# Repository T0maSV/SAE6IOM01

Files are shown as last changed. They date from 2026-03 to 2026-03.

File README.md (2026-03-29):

# Simulateur de Parking Connecté — SAÉ6.IOM.01

> **Livrable final : [`VIALON_Thomas_rapport_final.pdf`](./VIALON_Thomas-rapport_final.pdf)** (Livrable 6)

## Présentation

Projet de fin d'études réalisé dans le cadre du BUT Réseaux & Télécommunications, parcours Internet des Objets et Mobilité (IOM), à l'IUT de Blois — Année universitaire 2025-2026.

Le projet consiste en la conception et la réalisation d'une maquette fonctionnelle de parking connecté intégrant :

- Détection de véhicules par trois technologies de capteurs (effet Hall, Reed/ILS, infrarouge)
- Communication longue portée LoRa 868 MHz entre les capteurs et le serveur
- Contrôle d'accès par badge RFID (13.56 MHz) avec barrière motorisée et sécurité anti-écrasement par capteur ultrason
- Serveur embarqué sur Raspberry Pi 3 (Flask, InfluxDB, SQLite)
- Interface Web de supervision accessible depuis le Raspberry Pi 4 commun

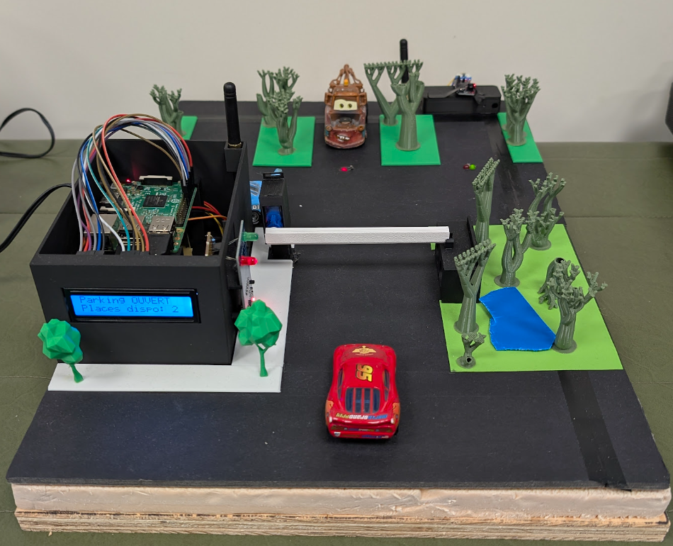
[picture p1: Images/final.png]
Maquette du simulateur de parking connecté


## Arborescence du dépôt
```
├── VIALON_Thomas_rapport_final.pdf   # Livrable 6 — Rapport final
├── VIALON_CdCT_V1.pdf               # Livrables 2 & 3 — Cahier des Charges Technique
├── VIALON_Thomas_Devis.pdf           # Livrable 4 — Devis
├── diagramme_gantt.png               # Livrable 1 — Diagramme de Gantt
│
├── Programme/                        # Intégralité des programmes du projet
│   └── Final/
│       ├── ESP_Parking/              # ESP32 LoRa — Nœud capteur (3 places)
│       ├── ESP_Passerelle/           # ESP32 LoRa — Gateway LoRa/Série
│       ├── ESP_Barrier/              # ESP32 — Contrôleur d'accès (RFID + barrière)
│       └── RPi3/                     # Raspberry Pi 3 — Serveur (app.py, index.html, reset_db.py)
│
├── 3D/                               # Modélisation et fichiers d'impression 3D
│   ├── Maquette Parking.shapr.step   # Projet complet (ensemble des pièces)
│
├── Fritzing/                         # Schémas électroniques (CAO)
│   └── *.fzz                         # Circuits réalisés et envisagés pour le projet
│
└── Images/                           # Photos et captures du projet
```

## Technologies utilisées

| Domaine | Technologies |
|---|---|
| Communication sans fil | LoRa 868 MHz, Wi-Fi 2.4 GHz, RFID 13.56 MHz |
| Microcontrôleurs | ESP32 (Heltec LoRa V2), ESP32 DevKit |
| Serveur | Raspberry Pi 3, Python, Flask |
| Bases de données | InfluxDB (séries temporelles), SQLite (utilisateurs/badges) |
| Électronique | PCB gravés par CNC (Fritzing), soudure manuelle |
| Fabrication | Impression 3D PLA, modélisation Shapr3D |

## Auteur

**Thomas VIALON** — BUT R&T 3ᵉ année, parcours IOM — IUT de Blois

Encadrant : M. Xavier JEANNERET

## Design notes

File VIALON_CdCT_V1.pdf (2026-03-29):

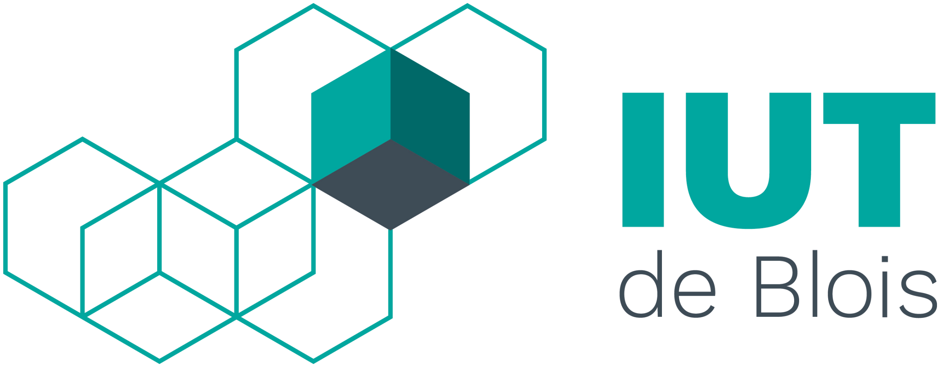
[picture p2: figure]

IUT DE BLOIS

Département Réseaux et Télécommunications

## CAHIER DES CHARGES TECHNIQUE

# SAE6IOM01

## Simulateur d’un parking connecté

Auteur :
Thomas VIALON

Date de remise :
11 février 2026

Document technique universitaire - Usage pédagogique uniquement

## Suivi des modifications

Version | Date | Auteur | Description des modifications
0.1 | 03/02/2026 | T. VIALON | Création du document et analyse du besoin (CdCF).
0.5 | 05/02/2026 | T. VIALON | Définition de l’architecture technique (Hardware/Software) et choix des so-lutions.
0.9 | 10/02/2026 | T. VIALON | Ajout du budget prévisionnel et du planning (Gantt). Rédaction des scé-narios.
1.0 | 11/02/2026 | T. VIALON | Validation finale pour diffusion. Mise en forme et intégration des sché-mas.

## Liste de diffusion

— Destinataire : M. Xavier JEANNERET (Enseignant responsable et client)

CdCT - Simulateur Parking | SAE6IOM01

## Table des matières

1 Introduction et Contexte | 3
2 Solutions Techniques et Matériel | 6
3 Organisation Générale de la Solution | 10
4 Budget Prévisionnel | 12
5 Calendrier Prévisionnel | 13

## 1 Introduction et Contexte

### 1.1 Rappel du besoin (CdCF)

Le besoin exprimé consiste a concevoir la maquette d’un parking connecté. Le client attend notamment de ce projet les fonctionnalités suivantes :
— Collecte des données avec historique : places occupés, temps occupé, contrôle d’accès.
— Affichage local du nombre de places libres.
— Barrière automatique avec contrôle d’accès par badge.
— Repérage des places par led : vert=libre, rouge=occupé.
— Log d’accès et statistiques d’occupation
Ce besoin devra être présenté au client le 20 mars 2026 durant une présentation.

### 1.2 Technologies envisagées

Pour répondre aux fonctionnalités du cahier des charges, plusieurs familles technologiques ont été étudiées. Cette section explore les différentes options techniques disponibles pour chaque brique fonctionnelle du système.

### 1. Coeur du système et Supervision (Serveur) Le système nécessite une unité

centrale puissante capable d’orchestrer les flux de données, de gérer une base de données et de servir une interface graphique complexe.
— Microcontrôleur standard : Trop limité en mémoire RAM et en puissance de calcul pour héberger un serveur de base de données complet et gérer un affichage graphique haute résolution.
— Nano-ordinateur : Cette solution offre un système d’exploitation complet (Linux), permettant le multitâche, la gestion native de périphériques USB/HDMI et l’hébergement de bases de données (SQL/NoSQL). C’est la technologie privilégiée pour le rôle de serveur central.

### 2. Unités de Traitement Déportées (Noeuds de Parking) Afin de gérer les capteurs

et les indicateurs lumineux au plus près des places de parking, une intelligence locale est nécessaire.
— Architecture centralisée (Tout filaire) : Tirer des câbles depuis chaque capteur jusqu’au serveur central est inenvisageable sur une infrastructure étendue (problème de chute de tension et travaux multiples sur l’ensemble du parking). — Architecture distribuée (Noeuds IoT) : L’utilisation de microcontrôleurs déportés est requise.
— Microcontrôleur simple (ex : Arduino Uno) : Nécessite l’ajout de modules externes (Shields) pour communiquer, ce qui augmente l’encombrement. — SoC (System on Chip) Communicant (ex : ESP32) : Ces puces intègrent le processeur et la communication (Wi-Fi/LoRa) sur le même circuit. Elles permettent de créer des îlots autonomes capables de gérer plusieurs places simultanément.

### 3. Architecture Réseau et Topologie La simulation d’un parking de type "Smart

City" impose une réflexion sur le transport des données et l’interconnexion des élé-

ments.

— Topologie Réseau : Une architecture en étoile est envisagée pour sa robustesse.
— Les Noeuds (places de parking) sont périphériques et autonomes.
— Une Passerelle (Gateway) centrale est nécessaire. Le nano-ordinateur ne disposant pas nativement d’interface radio longue portée, un microcontrôleur dédié (faisant office de modem) devra assurer l’interface entre les trames radio et le serveur via une liaison série (USB/UART).
— Choix du protocole de communication :
— Wi-Fi : Débit élevé mais consommation énergétique importante. Peu adapté pour des capteurs sur batterie, mais pertinent pour la communication entre le serveur et la tablette de supervision.
— Bluetooth (BLE) : Très faible consommation mais portée trop courte pour une infrastructure étendue.
— LPWAN (LoRa) : Ce protocole offre une excellente pénétration des obstacles et une longue portée. C’est la technologie retenue pour le lien Noeuds ↔ Passerelle car elle simule parfaitement les contraintes industrielles (faible débit, longue portée).

### 4. Détection de présence (Véhicules) La fiabilité de la détection est critique. Plu-

sieurs principes physiques sont comparés :
— Optique (IR / Ultrason) : Détection par réflexion d’onde. Simple à mettre en oeuvre, mais sensible aux salissures et aux interférences lumineuses en extérieur.
— Infrarouge passif (PIR) : Détecte le mouvement de chaleur. Inadapté car incapable de détecter un véhicule immobile moteur froid.
— Magnétique (Magnétomètre) : Mesure la variation du champ magnétique terrestre (boussole). Très réaliste pour de grosse masse métallique tel qu’un véhicule mais complexe à calibrer sur une maquette.
— Magnétique (Effet Hall / Reed) : Détection binaire de proximité d’un champ magnétique (aimant). Cela nécessite à notre maquette l’ajout d’aimants sur les véhicules miniatures
— Interrupteur Reed (ILS) : Contact mécanique sous vide. Simple mais sujet à l’usure mécanique (vibrations).
— Capteur à effet Hall : Composant électronique sans pièce mobile. Très robuste, durable et insensible à la saleté.

### 5. Interface Utilisateur et Signalisation

— Signalisation des places : L’usage de LEDs est retenu. L’intégration peut se faire via des modules unitaires câblés ou via la conception d’un circuit imprimé (PCB).
— Affichage local : Pour indiquer le nombre de places restantes à l’entrée, un afficheur LCD piloté en I2C ou un écran OLED sont des standards robustes et peu énergivores par rapport à un écran HDMI complet.

### 6. Contrôle d’accès (Barrière et Identification)

— Motorisation :

— Moteur pas à pas : Offre une grande précision et un couple élevé, mais nécessite une électronique de commande (driver) complexe.
— Servomoteur : Permet un positionnement angulaire absolu (0-90°) simple via un signal PWM, idéal pour une barrière légère de maquette.
— Identification : La technologie RFID/NFC (13.56 MHz) est le standard industriel retenu pour le contrôle d’accès par badge (sans contact, sécurisé, passif).

## 2 Solutions Techniques et Matériel

Cette partie détaille les choix technologiques arrêtés pour répondre aux contraintes du cahier des charges. L’architecture retenue privilégie la décentralisation (Edge Computing) et la robustesse via l’utilisation d’un serveur dédié.

### 2.1 Solutions retenues

Architecture Informatique (Serveur et Supervision) Le système repose sur une architecture distribuée Client-Serveur :
1. Serveur de Projet (Raspberry Pi 3) : C’est le cerveau opérationnel du système. — Justification : Le choix de dédier un RPi3 (plutôt que d’utiliser uniquement le RPi4 commun) répond à un impératif de tolérance aux pannes. Le système de gestion du parking (base de données InfluxDB, scripts Python, gestionnaire MQTT/LoRa) doit rester fonctionnel même si l’interface d’affichage (RPi4) est éteinte ou déconnectée. Cela garantit la persistance des données.
2. Interface de Supervision (Raspberry Pi 4 Commun) :
— Justification : Le RPi4 est utilisé exclusivement comme client léger (Affichage Web). Cette séparation des tâches allège la charge processeur du serveur et respecte la consigne d’interaction tactile imposée.

Stratégie de Gestion des Données Le choix des bases de données est dicté par la nature hétérogène des informations à traiter. Une architecture hybride a été retenue :

— Données Temporelles (InfluxDB) : Pour l’historisation des capteurs (Monitoring), le choix s’est porté sur une base de données Time Series (InfluxDB) plutôt qu’une base relationnelle classique (MySQL).
— Justification : InfluxDB est optimisée pour l’écriture massive de données horodatées et permet des requêtes d’agrégation temporelle (ex : moyenne par heure) natives et rapides, indispensables pour les statistiques d’occupation. — Données Administratives (SQLite) : Pour la gestion des utilisateurs et des accès, le moteur SQLite a été préféré à un serveur Client-Serveur lourd (type MariaDB/PostgreSQL).
— Justification : Sa légèreté (base fichier sans processus serveur) est parfaitement adaptée aux ressources limitées d’un système embarqué, tout en garantissant l’intégrité des relations (Usagers ↔ Droits).

Serveur Web et Interface (Backend) Pour assurer la supervision depuis le Raspberry Pi 4 commun, le choix du serveur web s’est porté sur le micro-framework Flask (Python).
— Justification : Ce choix garantit une homogénéité logicielle totale. Le même script Python gère la réception des données LoRa, le stockage en base de données et la génération des pages Web.
— Performance : Contrairement à une pile LAMP (Linux-Apache-MySQL-PHP) trop lourde pour les ressources limitées du Raspberry Pi 3, Flask offre une solution légère et rapide, idéale pour de l’embarqué temps réel.

Connectivité Sans Fil (Hétérogénéité des protocoles) L’usage de trois protocoles distincts est justifié par leurs caractéristiques physiques complémentaires :
— LoRa (868 MHz) : Choisi pour sa capacité de pénétration et sa longue portée, indispensable pour relier des capteurs au sol (soumis aux interférences) vers la passerelle sans infrastructure câblée lourde.
— Wi-Fi (2.4 GHz) : Choisi pour sa large bande passante, nécessaire au transport des flux graphiques vers le tableau de bord de supervision.
— RFID (13.56 MHz) : Standard industriel retenu pour la sécurité du contrôle d’accès (identification unique et infalsifiable des badges).

Détection et Signalisation (Approche Comparative) Pour une approche plus pédagogique, l’îlot de parking ne se limitera pas à une seule technologie mais servira de banc de test comparatif en situation réelle.
— Stratégie Hybride : Trois places distinctes seront équipées de technologies différentes pour évaluer leur fiabilité respective face aux aléas (luminosité, positionnement du véhicule) :
1. Technologie Magnétique Active : Capteur à effet Hall (KY-003).
2. Technologie Magnétique Passive : Interrupteur Reed (ILS / Ampoule Reed).
3. Technologie Optique : Capteur Infrarouge de réflexion (KY-032 ou KY-033). — Intégration (PCB) : Un circuit imprimé unique ("Hub Parking") sera conçu pour accueillir ces trois types de capteurs simultanément. Cela éliminera les biais liés à une mauvaise connectique (faux contacts sur breadboard).

Interface d’Information Locale (Entrée du Parking) Pour communiquer avec l’usager avant la barrière (message de bienvenue, nombre de places), le choix s’est porté sur un écran LCD alphanumérique.

— Technologie : Afficheur LCD équipé d’un module d’interface série I2C.
— Justification technique :
— Lisibilité : Contrairement aux écrans OLED standards (0.96") jugés trop petits pour être lus confortablement sur la maquette, le LCD offre des caractères de grande taille et un fort contraste.
— Sobriété des ressources : L’utilisation d’un écran HDMI a été écartée car disproportionnée (coût, consommation, complexité logicielle) pour le simple affichage de texte brut.
— Câblage simplifié : Le choix de l’interface I2C permet de piloter l’écran avec seulement 2 fils de données (SDA/SCL) reliés au Raspberry Pi 3, contre 6 à 10 fils pour un écran LCD standard parallèle.

Mécanique d’Accès et Sécurité Active La gestion de la barrière intègre une boucle de sécurité simulant les normes réelles. Pour garantir une réactivité immédiate, l’architecture privilégie une liaison filaire.

— Motorisation : Choix du Servomoteur qui permet un positionnement angulaire absolu relativement simple pour notre simulation.
— Identification : Lecteur RFID (RC522) pour valider l’ouverture.
— Sécurité (Anti-écrasement) : Choix d’un capteur de proximité Infrarouge (KY-
032) placé après la barrière.

— Justification du choix : Contrairement au capteur ultrason (HC-SR04) qui possède une "zone aveugle" de quelques centimètres et un cône de détection large, le capteur infrarouge offre une détection précise à très courte portée. Il simule efficacement une "barrière immatérielle" industrielle, empêchant la fermeture du bras tant que le véhicule n’a pas totalement franchi la zone de danger.

### 2.2 Liste du matériel

### 2.2.1 Matériel disponible

Les éléments suivants seront prélevés sur le stock "SAE6IOM01" :
— Unités de traitement :
— 1x Raspberry Pi 3 (Serveur de Projet).
— 2x ESP32 LoRa (1x Noeud Capteur, 1x Passerelle Gateway).
— 1x ESP32 Standard (Gestionnaire d’accès).
— Sources d’alimentation diverses (prise secteur USB-A et câble micro-USB vers USB-A)
— 1x Écran LCD I2C (Affichage places libres, connecté au RPi3).
— Capteurs Comparatifs (Parking) :
— 1x Capteur à effet Hall (KY-003).
— 1x Interrupteur Reed (Module KY-021 ou ampoule).
— 1x Capteur Infrarouge (KY-032 ou KY-033).
— 3x Paires de LEDs (Verte/Rouge).
— Accès et Sécurité :
— 1x Servomoteur (Barrière).
— 1x Kit RFID RC522.
— 1x Capteur IR ou Ultrason (Sécurité anti-écrasement barrière).

### 2.2.2 Matériel spécifique à produire

Électronique (Conception et Gravure CNC) Au lieu d’un câblage "volant" sur plaque d’essai, le système sera modulaire pour être conforme aux exigences du client :
— PCB "Hub Parking" : Accueille le microcontrôleur ESP32 et distribue l’alimentation. Il intègre des connecteurs robustes (borniers ou JST) pour relier les capteurs déportés (Hall, IR, Reed) sans soudure directe.
— PCB "Passerelle" : Carte d’interface connectée au Raspberry Pi 3. Elle assure le maintien mécanique de l’ESP32 LoRa et de son antenne, garantissant une connexion série (UART/USB) stable.
— PCB "Signalisation" : Petits circuits imprimés intégrant la LED et sa résistance de protection. Conçus pour s’insérer parfaitement dans les potelets imprimés en 3D.
— PCB "Contrôleur d’Accès" : Carte regroupant l’ESP32 de gestion, le connecteur du servomoteur et les interfaces pour le lecteur RFID et le capteur d’anti-écrasement barrière. Prévision d’un condensateur de découplage sur le PCB pour protéger l’ensemble du circuit des parasites du moteur.

Conception CAO et Impression 3D L’intégration vise un rendu d’une maquette au maximum réaliste :

— Zone Barrière : Conception de l’ensemble cinématique comprenant : — Le boîtier moteur intégrant le servomoteur.
— Le boîtier "technique" intégrant le lecteur RFID et l’ESP32.
— La barrière mobile (lisse) fixée sur l’axe du moteur.
— Le repose-barrière pour stabiliser la lisse en position fermée.
— Un support pour le lecteur RFID
— Zone Parking : Potelets de signalisation (pour les PCBs LEDs) et boîtier de protection pour le "Hub Parking" (dissimulé sous la maquette).
— Gateway : Boîtier de protection pour l’ESP32 passerelle connecté au RPi3.
— Serveur du système : Boîtier de protection pour le RPI3. Il pourra prendre la forme d’un bâtiment simulant l’accueil du site.

## 3 Organisation Générale de la Solution

Cette section détaille l’architecture matérielle, la structure des données et les scénarios fonctionnels qui régissent les interactions entre les composants.

### 3.1 Architecture Matérielle Distribuée

Le système s’articule autour d’un noeud central (le Serveur RPi3) qui orchestre des périphériques filaires et radio.

1. Le Coeur (Serveur RPi3) : Il héberge l’intelligence du système. Il alimente et pilote via ses ports USB :
— La Passerelle LoRa (ESP32) pour la réception des données du parking. — Le Contrôleur d’Accès (ESP32) pour le pilotage temps réel de la barrière et du RFID.
2. La Zone Parking (Radio LoRa) : Les îlots de capteurs sont énergétiquement autonomes (alimentation secteur USB dédiée). Ils traitent les signaux des trois technologies de capteurs (Hall, IR, Reed) et transmettent les changements d’état via le protocole LoRa (868 MHz) pour simuler l’éloignement géographique.
3. La Supervision (Interface Commune) : L’interaction utilisateur respecte la charte du projet global via le Raspberry Pi 4 commun.
— Intégration Web : Le RPi3 héberge un serveur web léger qui expose le Tableau de Bord.
— Rôle du RPi4 : Il agit comme un portail d’accès. Une page index centrale redirige (ou intègre via ‘iframe‘) vers l’interface web générée par le RPi3, garantissant ainsi l’indépendance du code "Parking" vis-à-vis des autres projets étudiants.

### 3.2 Architecture Logicielle et Données

L’intelligence du système, hébergée sur le Raspberry Pi 3, s’appuie sur deux espaces de stockage complémentaires :

1. Base "Métier" (SQLite) Elle stocke la configuration statique du parking.
— Contenu : Table des Usagers (Nom, Prénom), Table des Badges (UID RFID), Table des Droits (Accès autorisé/interdit).
— Interaction : Elle est consultée en lecture à chaque présentation de badge à l’entrée.
2. Base "Télémétrie" (InfluxDB) Elle stocke le flux dynamique des événements.
— Contenu : Mesures brutes (Place ID + État 0/1 + Timestamp), Type de capteur source (Hall/IR/Reed).
— Interaction : Elle est alimentée en écriture continue par la passerelle LoRa et consultée par le Dashboard pour l’affichage des courbes.

### 3.3 Scénarios Fonctionnels

Le système réagit selon deux boucles d’interaction principales :

Scénario A : Contrôle d’Accès (Flux Filaire)
1. L’usager présente son badge sur le lecteur de l’ESP32 "Barrière".
2. L’ESP32 transmet l’UID via USB au script Python du RPi3.
3. Le RPi3 interroge la base SQLite. Si l’UID est reconnu :
— Le RPi3 renvoie l’ordre "OUVRIR" à l’ESP32.
— L’ESP32 actionne le servomoteur.
— Une entrée est ajoutée dans les logs d’accès.
4. Si l’UID est inconnu, la barrière reste fermée et l’écran affiche "Refusé".

Scénario B : Supervision des Places (Flux LoRa)
1. Un véhicule se gare sur une place (détection par capteur Hall, IR ou Reed).
2. L’ESP32 "Parking" détecte le changement d’état et envoie une trame LoRa contenant l’ID de la place et son nouvel état.
3. La passerelle (Gateway) reçoit la trame et la transmet en USB au RPi3.
4. Le RPi3 enregistre la donnée brute dans InfluxDB.
5. Le RPi3 met à jour directement l’écran LCD connecté sur son bus I2C pour afficher le nouveau nombre de places disponibles.
6. L’interface Web (Dashboard) se met à jour automatiquement.

### 3.4 Schéma Synoptique des Interconnexions

Le diagramme ci-dessous synthétise les flux physiques (câblage) et logiques (protocoles) :

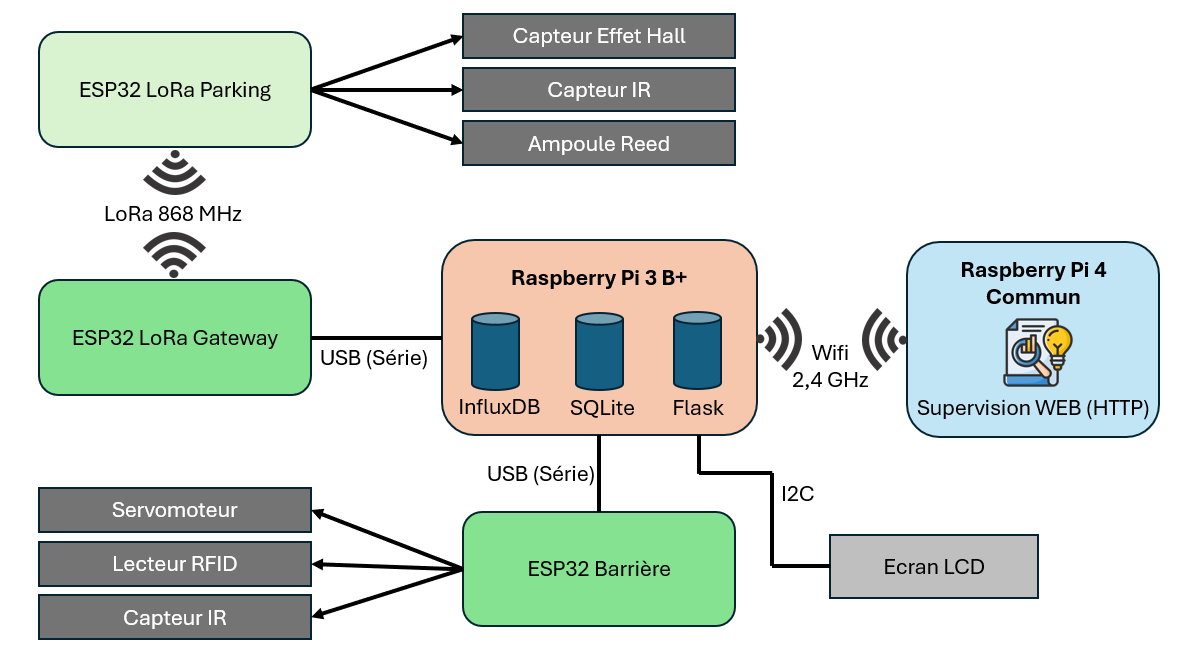
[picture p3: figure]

FIGURE 1 – Architecture globale : Matériel, Réseaux et Données

## 4 Budget Prévisionnel

Ce budget présente une valorisation complète du projet. Il intègre le coût du matériel mis à disposition par l’IUT (amortissement matériel) ainsi que les coûts de fabrication (consommables) nécessaires à la réalisation de la maquette.

Désignation | Justification & Provenance | Qté | Coût (Est.)
| Matériel Informatique & Réseau
Raspberry Pi 3 B+ | Serveur de projet (Stock IUT) | 1 | 40.00 e
Microcontrôleurs ESP32 | 2x LoRa + 1x Std (Stock IUT) | 3 | 45.00 e

Capteurs & Actionneurs
Servomoteur + RFID | Kit Contrôle d’accès (Stock IUT) | 1 | 10.00 e
Lot Capteurs | Hall, IR, Reed, LEDs (Stock IUT) | 1 | 12.00 e
Écran LCD I2C | Affichage local (Stock IUT) | 1 | 6.00 e

Consommables & Fabrication
Filament PLA | Impression 3D (Barrière, Boî-tiers) | 200g | 5.00 e
Plaque Cuivre FR4 | Réalisation des 4 PCBs | 1 | 4.00 e
Carton Plume (Mousse) | Structure et base de la maquette | 2 | 10.00 e
Composants passifs | Résistances, Condensateurs, Connecteurs | Lot | 3.00 e
Câblage | Câbles USB, Cavaliers, Étain | Lot | 5.00 e
Bloc Secteur USB | Alimentation ESP Parking | 1 | 5.00 e
VALEUR TOTALE DU PROJET | | | 145.00 e
Dont reste à charge (Consommables) | | | 32.00 e

TABLE 1 – Budget prévisionnel valorisé

Ce budget est fourni à titre indicatif. Les coûts et quantités sont susceptibles d’évoluer en fonction des contraintes d’approvisionnement et des ajustements techniques mineurs en cours de réalisation.

## 5 Calendrier Prévisionnel

La planification du projet s’étend du 3 février au 20 mars 2026. Le respect des délais repose sur une identification claire des livrables et des points de validation (Checkpoints) avec le client.

### 5.1 Phasage du projet

Le projet est découpé en six phases opérationnelles, alternant études théoriques et réalisation technique :

— Phase 1 : Cadrage (3/02 - 5/02)
Appropriation du sujet, analyse du besoin et initialisation de la planification (Gantt).
— Phase 2 : Étude Technique (5/02 - 11/02)
Rédaction du Cahier des Charges Technique (CdCT), définition de l’architecture matérielle et sélection des composants.
— Phase 3 : Chiffrage et Validation (11/02 - 13/02)
Établissement du budget prévisionnel et Checkpoint client pour valider le lancement de la fabrication.
— Phase 4 : Réalisation et Intégration (02/03 - 18/03)
C’est le coeur de la production technique :
— Hardware : Gravure et soudure des PCBs, impression 3D de la maquette (Barrière, Îlots).
— Software : Programmation des ESP32 et configuration du serveur Raspberry Pi 3. — Intégration : Assemblage final et raccordement au RPi4 commun.
— Phase 5 : Documentation (02/03 - 19/03)
Rédaction du rapport final, des notices d’utilisation et commentaires du code source, réalisée en parallèle de la phase de production.
— Phase 6 : Livraison (19/03 - 20/03)
Préparation du support de présentation et soutenance finale du produit devant le client.

### 5.2 Diagramme de Gantt

Le planning visuel ci-dessous détaille l’enchaînement des tâches et l’avancement prévisionnel.

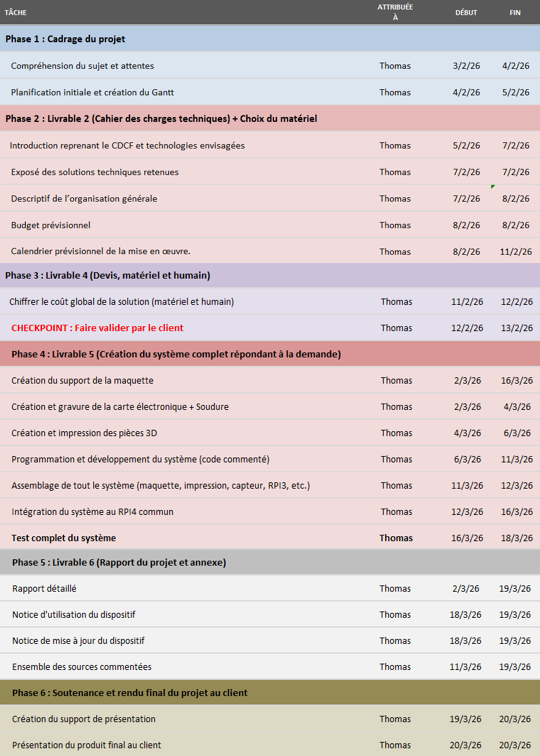
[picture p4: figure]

FIGURE 2 – Planning prévisionnel détaillé (Phases 1 à 6)

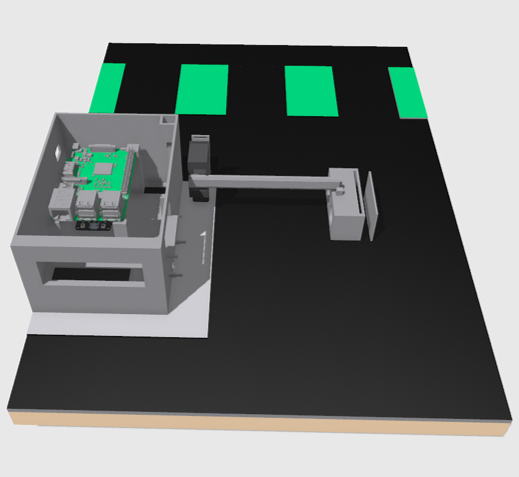
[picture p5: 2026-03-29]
Images/maquette.png

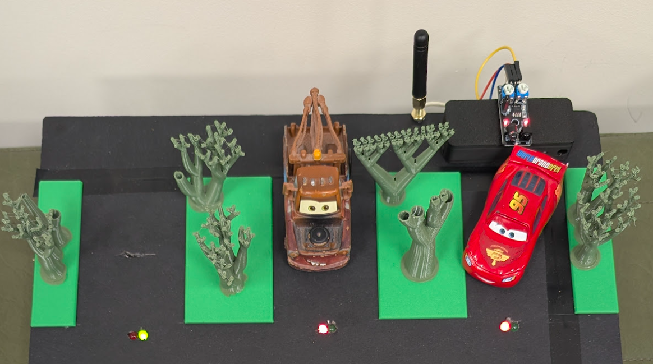
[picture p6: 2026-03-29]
Images/parking.png

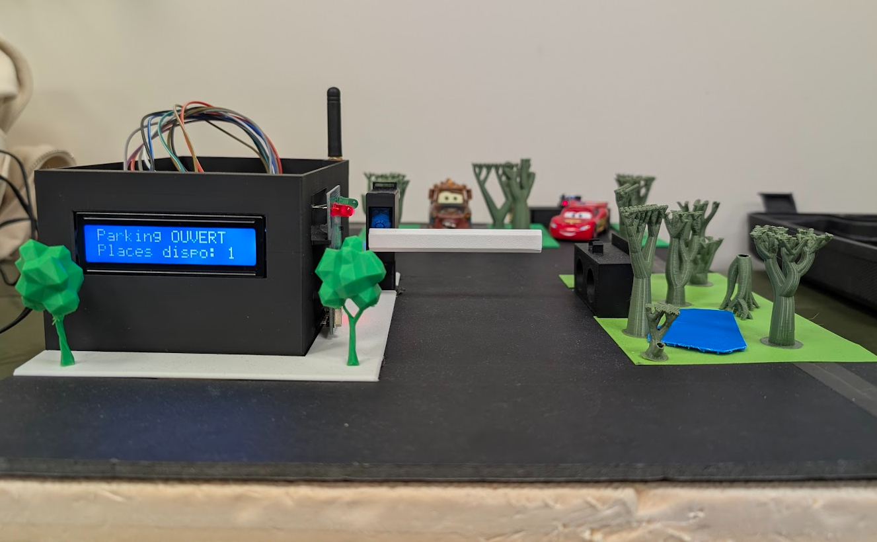
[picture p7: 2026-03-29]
Images/parking_avant.png

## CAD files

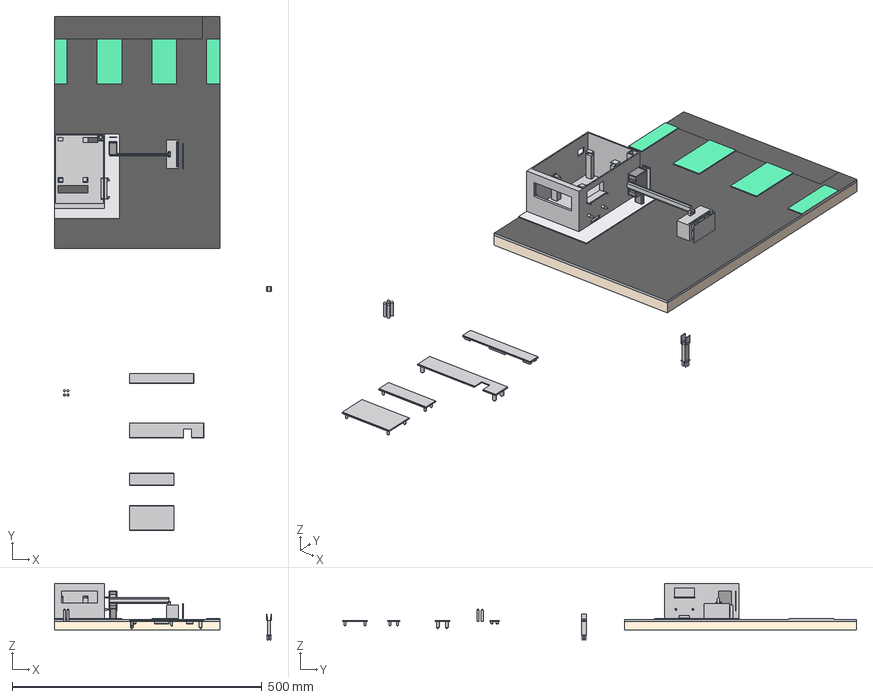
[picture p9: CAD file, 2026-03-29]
3D/Maquette Parking.shapr.step
435.0 x 1030.0 x 114.4 mm
Barrière
Ultrason
Trottoir
Support
[Idée] Support
Boîte
Porte
Accueil
Support Maquette

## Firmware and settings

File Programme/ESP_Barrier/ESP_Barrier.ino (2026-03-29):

#include <SPI.h>
#include <MFRC522.h>
#include <ESP32Servo.h>

// ==========================================
// 📍 PINOUT (TON PCB BARRIÈRE)
// ==========================================
// --- RFID RC522 ---
// SDA (SS) -> 21
// SCK      -> 18
// MOSI     -> 23
// MISO     -> 19
// RST      -> 22
#define SS_PIN  21
#define RST_PIN 22
#define LED_ROUGE 25
#define LED_VERTE 26
#define SERVO_PIN 13
#define TRIG_PIN 33
#define ECHO_PIN 32

MFRC522 rfid(SS_PIN, RST_PIN);
Servo barriere;

bool barriereOuverte = false;

void setup() {
  Serial.begin(115200);
  
  // Cette ligne magique permet au Raspberry Pi de détecter qui est branché sur quel port USB !
  Serial.println("DEVICE_TYPE=BARRIERE"); 

  // Config LEDs
  pinMode(LED_ROUGE, OUTPUT);
  pinMode(LED_VERTE, OUTPUT);
  digitalWrite(LED_ROUGE, HIGH);
  digitalWrite(LED_VERTE, LOW);

  // Config HC-SR04
  pinMode(TRIG_PIN, OUTPUT);
  pinMode(ECHO_PIN, INPUT);

  // Config Servomoteur
  ESP32PWM::allocateTimer(0);
  barriere.setPeriodHertz(50);
  barriere.attach(SERVO_PIN, 500, 2400);
  barriere.write(0); // Fermée par défaut

  // Config RFID
  SPI.begin();
  rfid.PCD_Init();
}

void loop() {
  // ----------------------------------------------------
  // 1. ÉCOUTE DU RASPBERRY PI (A-t-on reçu l'ordre d'ouvrir ?)
  // ----------------------------------------------------
  if (Serial.available() > 0) {
    String ordre = Serial.readStringUntil('\n');
    ordre.trim(); // Enlever les espaces invisibles
    
    if (ordre == "OUVRIR" && !barriereOuverte) {
      sequenceOuverture();
    }
  }

  // ----------------------------------------------------
  // 2. ÉCOUTE DU LECTEUR RFID (Y a-t-il un badge ?)
  // ----------------------------------------------------
  if (!barriereOuverte && rfid.PICC_IsNewCardPresent() && rfid.PICC_ReadCardSerial()) {
    
    String uid_lu = "";
    for (byte i = 0; i < rfid.uid.size; i++) {
      uid_lu += String(rfid.uid.uidByte[i] < 0x10 ? " 0" : " ");
      uid_lu += String(rfid.uid.uidByte[i], HEX);
    }
    uid_lu.toUpperCase();
    
    // On envoie l'UID au Raspberry Pi pour qu'il vérifie dans la BDD
    Serial.print("UID=");
    Serial.println(uid_lu);
    
    rfid.PICC_HaltA(); // On met le badge en pause pour ne pas spammer
    delay(1000);       // Petite pause anti-rebond
  }
}

// ==========================================
// ⚙️ FONCTION D'OUVERTURE AVEC SÉCURITÉ ULTRASON
// ==========================================
void sequenceOuverture() {
  barriereOuverte = true;
  digitalWrite(LED_ROUGE, LOW);
  digitalWrite(LED_VERTE, HIGH);
  
  barriere.write(90); // Lève la barrière
  delay(3000);        // Laisse passer la voiture pendant 3 sec
  
  // --- SECURITE ANTI-FERMETURE (HC-SR04) ---
  while (voitureSousBarriere()) {
    // Tant qu'une voiture est détectée sous la barrière (distance < 10cm), on attend !
    delay(500); 
  }
  
  // La voie est libre, on ferme
  barriere.write(0);
  digitalWrite(LED_VERTE, LOW);
  digitalWrite(LED_ROUGE, HIGH);
  barriereOuverte = false;
  
  // On prévient le RPi que c'est terminé
  Serial.println("BARRIERE_FERMEE");
}

// ==========================================
// 📏 FONCTION DE MESURE DE DISTANCE (AVEC DEBUG)
// ==========================================
bool voitureSousBarriere() {
  digitalWrite(TRIG_PIN, LOW);
  delayMicroseconds(2);
  digitalWrite(TRIG_PIN, HIGH);
  delayMicroseconds(10);
  digitalWrite(TRIG_PIN, LOW);
  
  long duree = pulseIn(ECHO_PIN, HIGH, 30000); // Timeout 30ms
  
  if (duree == 0) {
    Serial.println("[HC-SR04] Erreur : Aucune reponse (Distance = 0)");
    return false; 
  }
  
  float distance = (duree / 2.0) * 0.0343;
  
  // Affichage dans la console pour comprendre ce que voit le capteur
  Serial.print("[HC-SR04] Distance mesuree : ");
  Serial.print(distance);
  Serial.println(" cm");
  
  // J'ai monté le seuil à 15 cm pour tester facilement avec la main
  if (distance > 1.0 && distance < 8.0) {
    Serial.println(">>> OBSTACLE DETECTE ! Je bloque la fermeture.");
    return true; 
  }
  
  return false;
}

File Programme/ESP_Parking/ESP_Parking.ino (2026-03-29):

#include <SPI.h>
#include <LoRa.h>

// ==========================================
// ⚙️ CONFIGURATION LORA (Heltec V2)
// ==========================================
#define LORA_SS    18
#define LORA_RST   14
#define LORA_DI0   26
#define LORA_FREQ  870300000 // 870.3 MHz
#define SECRET_KEY "SECURE_PARK|" // Notre "sécurité du pauvre"

// ==========================================
// 📍 CONFIGURATION DES BROCHES (GPIO)
// ==========================================
// Les tableaux permettent de gérer les 3 places d'un coup avec une boucle !
// Ordre : [Place 1 (IR), Place 2 (Hall), Place 3 (Reed)]
const int pinCapteurs[3] = {32, 22, 25};
const int pinLedRouge[3] = {13, 23, 17};
const int pinLedVerte[3] = {21,  2, 12};

// ==========================================
// ⏱️ GESTION DU TEMPS ET DES ETATS (Manœuvres)
// ==========================================
const unsigned long DELAI_MANOEUVRE = 5000; // 5 secondes de confirmation
bool etatActuel[3]     = {false, false, false}; // Ce que lit le capteur à l'instant T
bool etatConfirme[3]   = {false, false, false}; // L'état officiel après les 5 secondes
unsigned long chrono[3]= {0, 0, 0};             // Chronomètre pour chaque place

void setup() {
  Serial.begin(115200);
  Serial.println("\n--- DEMARRAGE ESP PARKING ---");

  // 1. Initialisation des broches
  for (int i = 0; i < 3; i++) {
    pinMode(pinCapteurs[i], INPUT_PULLUP); // PULLUP important pour Hall et Reed
    pinMode(pinLedRouge[i], OUTPUT);
    pinMode(pinLedVerte[i], OUTPUT);
    
    // Par défaut : Place Libre (VERT allumé, ROUGE éteint)
    digitalWrite(pinLedVerte[i], HIGH);
    digitalWrite(pinLedRouge[i], LOW);
  }

  // 2. Initialisation LoRa
  SPI.begin(5, 19, 27, 18);
  LoRa.setPins(LORA_SS, LORA_RST, LORA_DI0);
  
  if (!LoRa.begin(LORA_FREQ)) {
    Serial.println("ERREUR : LoRa introuvable !");
    while (1); // On bloque ici si erreur
  }
  Serial.println("LoRa OK. Freq: 870.3 MHz. Attente des vehicules...");
}

void loop() {
  bool changementDetecte = false;

  // On scanne les 3 places en boucle très rapidement
  for (int i = 0; i < 3; i++) {
    // Lecture du capteur (LOW = Aimant/Voiture détectée, HIGH = Rien)
    bool lecture = (digitalRead(pinCapteurs[i]) == LOW);

    // Si le capteur "saute" ou change d'état, on reset le chronomètre de cette place
    if (lecture != etatActuel[i]) {
      chrono[i] = millis(); 
      etatActuel[i] = lecture;
    }

    // Si l'état est stable pendant plus de 5 secondes...
    if ((millis() - chrono[i]) > DELAI_MANOEUVRE) {
      
      // ... et que cet état est différent de l'état officiel connu
      if (etatActuel[i] != etatConfirme[i]) {
        etatConfirme[i] = etatActuel[i]; // On valide le nouvel état
        changementDetecte = true;        // On prépare l'envoi LoRa
        
        // Mise à jour visuelle des LEDs
        if (etatConfirme[i] == true) { // OCCUPÉ
          digitalWrite(pinLedVerte[i], LOW);
          digitalWrite(pinLedRouge[i], HIGH);
          Serial.print("Place "); Serial.print(i+1); Serial.println(" : OCCUPEE !");
        } else {                       // LIBRE
          digitalWrite(pinLedRouge[i], LOW);
          digitalWrite(pinLedVerte[i], HIGH);
          Serial.print("Place "); Serial.print(i+1); Serial.println(" : LIBRE !");
        }
      }
    }
  }

  // S'il y a eu au moins un changement confirmé, on envoie UN SEUL message LoRa global
  if (changementDetecte) {
    envoyerTrameLoRa();
  }
}

// ==========================================
// 📡 FONCTION D'ENVOI LORA
// ==========================================
void envoyerTrameLoRa() {
  // Format : SECURE_PARK|1:O|2:L|3:O
  String message = String(SECRET_KEY);
  
  for (int i = 0; i < 3; i++) {
    message += String(i+1) + ":" + (etatConfirme[i] ? "O" : "L");
    if (i < 2) message += "|"; // Séparateur
  }

  LoRa.beginPacket();
  LoRa.print(message);
  LoRa.endPacket();

  Serial.println("-> Message LoRa envoye : " + message);
}
